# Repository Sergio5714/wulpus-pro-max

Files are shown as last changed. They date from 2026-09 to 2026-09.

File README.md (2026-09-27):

# WULPUS Pro Max
## Multi-mode Ultra-Low-Power Wearable Ultrasound Platform
> WULPUS Pro Max adopts the core analog front end of the original [WULPUS PRO design](https://github.com/pulp-bio/wulpus-pro), while extending its analog performance, firmware architecture, host connectivity, and software tooling. The project is independently developed and maintained by [Sergei Vostrikov](https://github.com/Sergio5714) and contributors.

<p align="center">
  WULPUS Pro Max main
  <br/>
  WULPUS Pro Max module with PolyCMUT transducer.
</p>

## Table of contents

- [Introduction](#introduction)
  - [Hardware photos](#hardware-photos)
  - [System diagram](#system-diagram)
  - [Specifications](#specifications)
- [Clone the repository](#clone-the-repository)
- [Structure of the repository](#structure-of-the-repository)
- [Documentation](#documentation)
- [Build Instructions](#build-instructions)
- [Host setup and operation](#host-setup-and-operation)
  - [WULPUS Pro Max WiFi host PCB (WiFi/USB CDC)](#wulpus-pro-max-wifi-host-pcb-wifiusb-cdc)
  - [WULPUS Pro Max + nRF52 DK + nRF Dongle (BLE)](#wulpus-pro-max--nrf52-dk--nrf-dongle-ble)
- [Citation](#citation)
- [Changelog](#changelog)
- [Authors](#authors)
- [License](#license)
  - [Limitation of Liability](#limitation-of-liability)

# Introduction

WULPUS Pro Max is a modular wearable ultrasound platform for research and
development. It combines a tightly integrated, flexible ultrasound acquisition
front end with a dedicated host board and a mature software stack. Together,
these components provide a complete path from transducer excitation and signal
acquisition to device control, data streaming, visualization, and analysis.

The modular architecture supports both wearable experiments and benchtop
operation:

- **Benchtop operation:** connect a single USB-C cable for power delivery,
  device configuration, and data transfer over USB CDC.
- **Wireless operation:** connect a LiPo battery with a 2-pin JST connector to the
  host board and use Wi-Fi/TCP for seamless, cable-free operation. The host
  board also provides integrated battery charging and protection.

> **Note:** The same USB-C cable can flash and update the entire device without
> external programming tools.

WULPUS Pro Max reliably delivers raw ultrasound data to the host system either
over the air or through a USB cable, with state-of-the-art pulse repetition
frequencies (PRFs) of up to **500 Hz**. The common Python software stack supports
both links, providing the same tools and workflows in either operating mode.

## Hardware photos

<table>
  <tr>
    <td colspan="2" align="center">
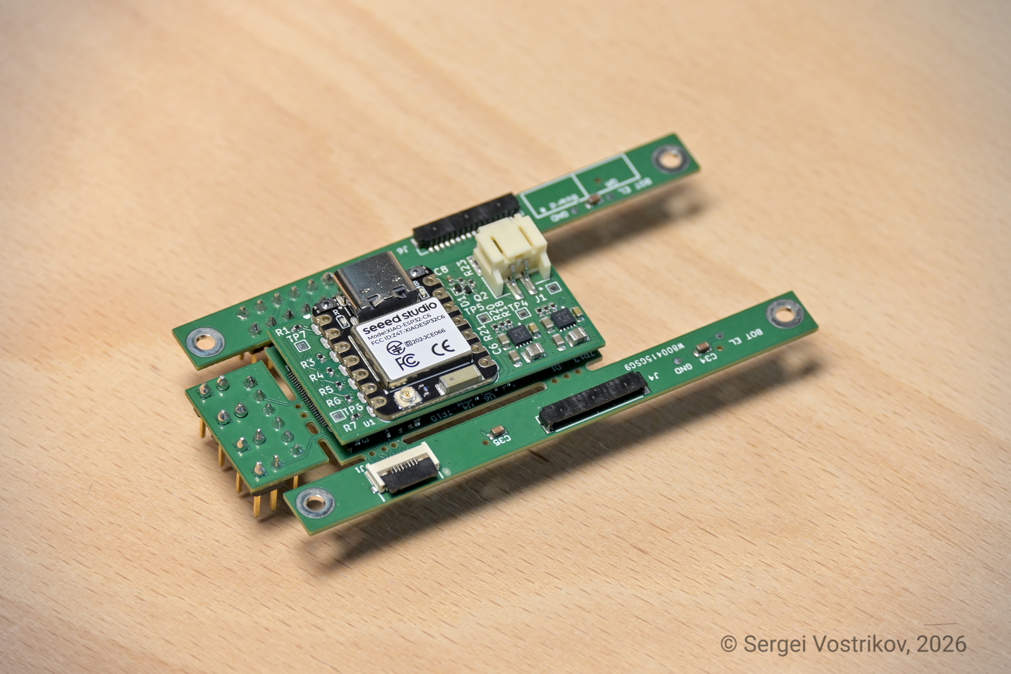
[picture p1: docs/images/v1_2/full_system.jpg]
WULPUS PRO Acquisition PCB connected to the WiFi host PCB
      
      <br/>
      Assembled WULPUS Pro Max system
    </td>
  </tr>
  <tr>
    <td width="50%" align="center">
      Top view of the WULPUS PRO Acquisition PCB
      <br/>
      WULPUS PRO Acquisition PCB<br/>
      (development version with test and debug headers)
    </td>
    <td width="50%" align="center">
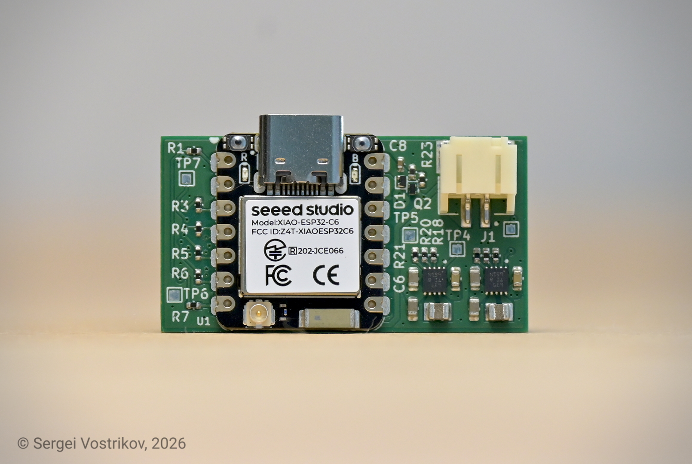
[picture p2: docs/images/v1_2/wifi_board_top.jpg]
Top view of the WULPUS Pro Max WiFi host PCB
      
      <br/>
      WULPUS Pro Max WiFi host PCB
    </td>
  </tr>
</table>

## System diagram

<p align="center">
  WULPUS Pro Max system diagram
  <br/>
  WULPUS Pro Max system diagram
</p>

## Specifications

WULPUS Pro Max builds on the original [WULPUS](https://github.com/Sergio5714/wulpus) platform and keeps the same low-power wearable ultrasound philosophy while making a substantial leap in specifications and extending the hardware and communication options. The table below compares the main features of WULPUS Pro Max with those of the original WULPUS platform.

| Feature | WULPUS<br>(v1.2.4) | WULPUS Pro Max |
| --- | --- | --- |
| Number of channels | 8, time-multiplexed | **16**, time-multiplexed |
| Supported transducers | PZT transducers | PZT transducers, **CMUTs** |
| Excitation amplitude | 15 V unipolar | **30 V** unipolar |
| Excitation frequency | ~100 kHz to 4 MHz | ~100 kHz to **10 MHz** |
| Transducer biasing | - | Indirect or direct **bias**, **-30 V or 30 V** |
| Analog front-end | 10 dB LNA + 30.8 dB PGA | 6 dB LNA + **70 dB VGA** |
| Receive-path<br>SNR | - | Approximately **45 dB** in the passband at 41.9 dB total gain;<br>**>=30 dB** at 3 MHz |
| Receive-path<br>bandwidth | &lt;1.4 MHz | Amplification-only: up to **14 MHz**;<br>end-to-end -3 dB: **1.4 MHz** |
| TGC support | No (fixed gain) | **Yes** (linear profile) |
| Maximum PRF | 50 Hz | **500 Hz**<br>(with WiFi host PCB over Wi-Fi/TCP or USB CDC) |
| Power budget at 50 Hz PRF | <=25 mW | <=40 mW |
| Data link | BLE | **USB**, **Wi-Fi**, or **BLE** |
| Form factor | 46 x 25 mm footprint | **40 x 20 mm** footprint |

Full WULPUS Pro Max specifications are available in [docs/full_specifications.md](docs/full_specifications.md).

# Clone the repository

Clone the public repository without its private development submodule:

```bash
git clone https://github.com/Sergio5714/wulpus-pro-max.git
```

The `hw/kicad_us_lib` submodule is an internal development library hosted in a
private repository. External users do not have access to it and do not need to
initialize it to use the released fabrication outputs. For editing the KiCad
designs, generate project-specific symbol and footprint libraries from the
symbols and footprints embedded in the corresponding project files. See the
[hardware README](hw/README.md#internal-kicad-library) for details.

Authorized developers can initialize the private submodule after cloning:

```bash
git submodule update --init --recursive
```

# Structure of the repository

The repository is organized into four top-level folders. See the README files
inside them for component-level details.

- [`hw`](hw) — PCB design and fabrication files.
- [`fw`](fw) — embedded firmware source code.
- [`sw`](sw) — Python software, graphical interfaces, and notebooks.
- [`docs`](docs) — project documentation and images.

# Documentation

- [Full system specifications](docs/full_specifications.md)
- [Host board options](docs/host_board_options.md)
- [PCB designs and fabrication](hw/README.md)
- Firmware:
  - [ESP32 host firmware](fw/esp32/README.md)
  - [MSP430 acquisition firmware](fw/msp430/README.md)
  - [Legacy nRF52 BLE firmware](fw/nrf52/README.md)
- [Python software and notebooks](sw/README.md)

For background information about the original WULPUS platform, see the
[legacy WULPUS User Manual](https://github.com/Sergio5714/wulpus/blob/main/docs/wulpus_user_manual.pdf).

# Build Instructions

The WULPUS Pro Max WiFi host PCB provides a one-cable setup and programming
workflow:

1. **Get hardware**

   Order the [Acquisition PCB](docs/images/v1_0/eval_board_main.jpg) and [WiFi host PCB](docs/images/v1_2/wifi_board_top.jpg) using the [PCBWay shared projects](hw/README.md#pcbway-shared-projects), or manufacture and assemble them yourself using the design files, schematics, and bills of materials linked in the [hardware guide](hw/README.md#included-pcb-designs).

2. **Install the host software**

   Follow the [Python software setup instructions](sw/README.md#how-to-get-started) on the host PC.

3. **Flash the firmware**

   - Connect the WiFi host PCB to the Acquisition PCB, then connect the host PCB to the PC with a single USB-C cable.
   - Follow the [firmware update guide](docs/firmware_update_guide.md) to install
     released ESP32 and MSP430 packages with the graphical updater.

   > No external programmer, adapter board, or additional programming cables are required for this workflow.

   > **Note:** The ESP32 and MSP430 firmware can be customized. Firmware
   > developers should follow the [ESP32 development guide](fw/esp32/docs/development_guide.md)
   > and [MSP430 development guide](fw/msp430/README.md#build-and-export-firmware)
   > to configure and compile custom images.

# Host setup and operation

WULPUS Pro Max supports multiple host-board configurations. See
[Host board options](docs/host_board_options.md) for a comparison. Instructions
for getting started with each configuration are provided below.

## WULPUS Pro Max WiFi host PCB (WiFi/USB CDC)

1. Connect the [WULPUS Pro Max WiFi host PCB](docs/images/v1_2/wifi_board_top.jpg) to the [Acquisition PCB](docs/images/v1_0/eval_board_main.jpg).
2. Connect the host PCB to the PC with a data-capable USB-C cable. This connection powers both PCBs.
3. Start Jupyter from the `sw` folder:

   ```bash
   uv run jupyter notebook
   ```

4. Open [`wulpus_pro_example.ipynb`](sw/wulpus_pro_example.ipynb) in the browser.
5. For a wired connection, select **USB CDC**, scan for devices, and open the ESP32-C6 port. For a wireless connection, first complete [WiFi provisioning](fw/esp32/docs/wifi_provisioning_guide.md), then select **WiFi** and discover the device.
6. Apply the acquisition configuration in the notebook and start acquisition.

For development with a standalone XIAO ESP32-C6, follow its [wiring and power requirements](fw/esp32/docs/development_guide.md#supported-boards) and the [pin mapping](fw/esp32/docs/development_guide.md#pin-mapping). This setup requires an Acquisition PCB with the MSP430 firmware already programmed.

## WULPUS Pro Max + nRF52 DK + nRF Dongle (BLE)

> The nRF52 BLE option may suit applications that need even lower power
> consumption than the WiFi host solution. It is a legacy, unsupported option
> and is not recommended for new setups. Using it requires additional
> integration work, including manual wiring, external power, and a separate
> programmer for the MSP430.

1. Connect the nRF52 DK to the Acquisition PCB using the pin mapping documented in [fw/nrf52/README.md](fw/nrf52/README.md).
2. Plug in the USB dongle and power the nRF52 DK via USB.
3. Check the dongle connection. The green LED should light up. If it does not, press the reset button on the nRF52 DK and try again.
4. After confirming dongle connectivity, power the Acquisition PCB through the connector or debug pin headers.
5. Start Jupyter from the `sw` folder:

   ```bash
   uv run jupyter notebook
   ```

6. Open [`wulpus_pro_example.ipynb`](sw/wulpus_pro_example.ipynb) in the browser, select **BLE**, and follow the notebook instructions to begin acquisition. Older notebook variants are archived under `sw/legacy`.

# Citation

Please cite our [arXiv preprint](https://arxiv.org/abs/2607.12137):

```bibtex
@article{vostrikov2026wulpuspro,
  title={WULPUS PRO: Multi-mode Ultra-Low-Power Wearable Ultrasound and Array Imaging with CMUT Support},
  author={Vostrikov, Sergei and Villani, Federico and Hirschi, Cedric and Lu, Jinhao and Welsch, Jonas and Angerer, Martin and Cretu, Edmond and Rohling, Robert and Cossettini, Andrea and Benini, Luca},
  journal={arXiv preprint arXiv:2607.12137},
  year={2026},
  url={https://arxiv.org/abs/2607.12137}
}
```

If you would like to cite this repository, please use:

```bibtex
@misc{wulpus_pro_repo_sergio5714_2026,
  title={WULPUS Pro Max: Multi-mode Ultra-Low-Power Wearable Ultrasound Platform (Independently Maintained)},
  author={Vostrikov, Sergei and Villani, Federico and Hirschi, Cedric and Cossettini, Andrea and Benini, Luca},
  year={2026},
  howpublished={GitHub repository},
  url={https://github.com/Sergio5714/wulpus-pro-max}
}
```

# Changelog

See [CHANGELOG.md](CHANGELOG.md) for release notes and main project changes.

# Authors

Since 2025,
[Sergei Vostrikov](https://scholar.google.com/citations?user=a0KNUooAAAAJ&hl=en)
(@Sergio5714) has independently maintained this repository and continued
developing WULPUS Pro Max, with contributions from others.

The initial WULPUS PRO system was developed from 2024 to 2025 as a research
project at the [Integrated Systems Laboratory (IIS)](https://iis.ee.ethz.ch/)
at ETH Zurich by:

- [Sergei Vostrikov](https://scholar.google.com/citations?user=a0KNUooAAAAJ&hl=en) (PCB design, firmware, software, open-sourcing)
- [Federico Villani](https://scholar.google.com/citations?user=5LgLMCEAAAAJ&hl=en) (PCB design, component selection)
- [Cedric Hirschi](https://www.linkedin.com/in/c%C3%A9dric-cyril-hirschi-09624021b/) (firmware, software)
- [Andrea Cossettini](https://scholar.google.com/citations?user=d8O91jIAAAAJ&hl=en) (supervision, project administration)
- [Luca Benini](https://scholar.google.com/citations?hl=en&user=8riq3sYAAAAJ) (supervision, project administration)

Additional contributors to the project were:

- [Sebastian Frey](https://scholar.google.com/citations?user=7jhiqz4AAAAJ&hl=en), ETH Zürich (design review)
- [Alfonso Blanco Fontao](https://www.linkedin.com/in/alfonso-blanco-fontao-b6214726/), ETH Zürich (design review, PCB fabrication coordination)
- [Ciara Giles Doran](https://www.linkedin.com/in/ciaragilesdoran/) (preliminary evaluation of the AD8338 VGA)

# License

The following files are released under Apache License 2.0 (`Apache-2.0`) (see `sw/LICENSE`):

- `sw/`

The hardware designs are released under Solderpad v0.51 (`SHL-0.51`):

- `hw/`

See the [hardware license table](hw/README.md#license) for the applicable license file and copyright holder for each PCB design.

Project-authored firmware code is generally licensed under Apache-2.0, as
identified in the source-file headers. Bundled vendor and third-party code
retains its original license, including BSD-style terms for Texas Instruments
sources and the Nordic Semiconductor license for Nordic SDK sources. See the
license notices and source headers in `fw/esp32/`, `fw/msp430/`, and `fw/nrf52/`
for the terms that apply to each file.

## Limitation of Liability

In no event and under no legal theory, whether in tort (including negligence), contract, or otherwise, unless required by applicable law (such as deliberate and grossly negligent acts) or agreed to in writing, shall any Contributor be liable to You for damages, including any direct, indirect, special, incidental, or consequential damages of any character arising as a result of this License or out of the use or inability to use the Work (including but not limited to damages for loss of goodwill, work stoppage, computer failure or malfunction, or any and all other commercial damages or losses), even if such Contributor has been advised of the possibility of such damages.

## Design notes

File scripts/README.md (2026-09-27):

# Development scripts

This directory contains maintainer and firmware-development utilities. Run all
commands from the repository root.

## Prerequisites

Follow the authoritative setup and build instructions before using these
scripts:

- [Python software setup](../sw/README.md#how-to-get-started)
- [ESP32 firmware development](../fw/esp32/docs/development_guide.md)
- [MSP430 firmware development](../fw/msp430/README.md#build-and-export-firmware)

The packaging scripts do not compile firmware. They validate and package the
outputs produced by these toolchains.

## ESP32 formatting

Check the formatting of project-owned ESP32 C sources:

```powershell
uv run --project sw python scripts/format_esp32_fw.py --check
```

`--check` only reports formatting differences and does not create or modify any
files. Apply formatting with:

```powershell
uv run --project sw python scripts/format_esp32_fw.py --fix
```

`--fix` modifies the project-owned `.c` and `.h` files in place under
`fw/esp32/main/` and `fw/esp32/components/`. It does not generate a separate
output file. Third-party sources under
`fw/esp32/components/msp430_programmer/ti/` are excluded.

## ESP32 release package

After building the XIAO ESP32-C6 firmware in `fw/esp32/build-xiao`, create the
validated release ZIP:

```powershell
uv run --project sw python scripts/package_esp32_release.py
```

The script reads these compiled files by default:

```text
fw/esp32/build-xiao/
|-- bootloader/bootloader.bin
|-- partition_table/partition-table.bin
`-- wulpus-pro-fw.bin
```

It creates the ignored `releases/` directory when needed and writes exactly one
release artifact:

```text
releases/wulpus-pro-max-esp32-<version>.zip
```

The ZIP contains:

```text
manifest.json
bootloader.bin
partition-table.bin
wulpus-pro-fw.bin
```

`manifest.json` contains the firmware version, ESP32-C6 target, flash settings,
fixed image offsets, and a SHA-256 hash for every binary.

Use `--build-dir PATH` to read build files from a different directory or
`--output FILE.zip` to select another output path. Packaging verifies that the
version embedded in `wulpus-pro-fw.bin` matches
`fw/esp32/firmware_version.txt`.

## MSP430 release package

Build the MSP430 **Debug** configuration in Code Composer Studio, then package
the generated TI-TXT image:

```powershell
uv run --project sw python scripts/package_msp430_release.py
```

By default, the script recursively searches
`fw/msp430/wulpus_msp430_firmware/` for a TI-TXT `.txt` or `.titxt` build. A
normal CCS Debug build is found at:

```text
fw/msp430/wulpus_msp430_firmware/Debug/wulpus_pro_msp430_firmware.txt
```

The script verifies its compiled firmware version against
`wulpus/firmware_version.h` and the MSP430 changelog. It also locates the TI
MSP430 21.6.0.LTS compiler used by the project and packages its original RTS
manifest and SPDX inventory with the DriverLib license. It creates the ignored
`releases/` directory when needed and writes two files:

```text
releases/
|-- wulpus-pro-max-msp430-<version>.zip
`-- wulpus-pro-max-msp430-<version>.zip.sha256
```

The ZIP contains the validated `.mspfw` image consumed by the ESP32 updater,
`SHA256SUMS.txt`, the project license, `THIRD_PARTY_NOTICES.txt`, and original
TI compliance files under `LICENSES/`. The adjacent `.sha256` file verifies the
complete release ZIP.

If more than one TI-TXT build exists, select it explicitly:

```powershell
uv run --project sw python scripts/package_msp430_release.py `
  --input path\to\wulpus_pro_msp430_firmware.txt
```

Use `--search-dir PATH` to change automatic discovery or `--output-dir PATH`
to place both generated files elsewhere. If the compiler is not in a standard
CCS installation directory, pass `--ti-compiler-dir PATH` or set
`TI_MSP430_CGT_DIR` to `ti-cgt-msp430_21.6.0.LTS`.

## PCB fabrication packages

Before packaging, manually regenerate and review all fabrication outputs and
documentation from the PCB source projects. In particular, regenerate the
KiCad fabrication and documentation outputs for the WiFi host PCB. This script
does not run KiCad, Altium Designer, design-rule checks, or output jobs.

Package the Acquisition PCB and WiFi host PCB:

```powershell
uv run --project sw python scripts/package_pcb_releases.py
```

The script reads only the `fabrication_outputs/` and `docs/` directories from
the two PCB projects. It creates four ignored release artifacts:

```text
releases/
|-- wulpus-pro-max-acquisition-pcb-1.0.0.zip
|-- wulpus-pro-max-acquisition-pcb-1.0.0.zip.sha256
|-- wulpus-pro-max-wifi-host-pcb-1.0.1.zip
`-- wulpus-pro-max-wifi-host-pcb-1.0.1.zip.sha256
```

The Acquisition PCB ZIP also contains `LICENSE_ETH`. The WiFi host PCB ZIP
also contains `CHANGELOG.md` and `LICENSE`. No editable PCB source files,
backup directories, firmware, or library files are included. Use
`--acquisition-version`, `--wifi-host-version`, or `--output-dir` to override
the defaults. The WiFi host version must match its latest changelog release.

## Installing release packages

This directory only documents development and packaging utilities. For the
supported graphical ESP32 and MSP430 update workflow, follow the
[firmware-update instructions](../docs/firmware_update_guide.md).

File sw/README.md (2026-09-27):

# WULPUS Pro Max software
This directory contains the WULPUS Pro Max Python API, graphical user interface components, Wi-Fi and serial transports, and example Jupyter notebooks.

`wulpus_pro_example.ipynb` is the supported main notebook for USB CDC, Wi-Fi,
and BLE operation. Older specialized notebooks are retained for reference in
`legacy/` and are not part of the current workflow.

The supported configuration implementation is the WULPUS Pro Max stack:

- `wulpus/rx_tx_conf_pro.py`: 16-channel TX/RX mask generation
- `wulpus/uss_conf_pro.py`: acquisition configuration and packet encoding
- `wulpus/config_package_pro.py`: configuration field definitions
- `wulpus/uss_conf_gui_pro.py`: configuration widgets
- `wulpus/gui.py`: transport-independent acquisition and visualization GUI
- `wulpus/wifi_link.py`: robust TCP transport and acquisition lifecycle
- `wulpus/wifi_discovery.py`: mDNS discovery
- `wulpus/usb_cdc_link.py`: native ESP32-C6 USB CDC transport
- `wulpus/ble_dongle.py`: legacy BLE-dongle serial transport
- `wulpus/device_config_gui.py`: persistent ESP32 configuration over USB CDC
- `wulpus/esp32_update.py`: validated ESP32-C6 release packages and flashing
  through uv-managed esptool
- `wulpus/msp430_update.py`: TI-TXT packaging, MSP430 upload, status,
  diagnostics, and update widgets over USB CDC or Wi-Fi
- `wulpus/npz_viewer.py`: interactive acquisition-file inspection and signal processing

`WulpusGuiSingleCh` depends on the `WulpusProCommunicationLink` protocol rather than a concrete transport, so it can operate with `WulpusBleDongle`, `WulpusProWiFiLink`, or `WulpusProUsbCdcLink`.

The ESP32 device-configuration section in `wulpus_pro_example.ipynb` uses
`WulpusProDeviceConfigGUI` to load and replace non-secret configuration over
USB CDC, set or clear write-only Wi-Fi credentials, and reboot to apply changes.
The GUI never reads stored SSIDs or passwords.

## Firmware updates

Use [`wulpus_pro_firmware_update.ipynb`](wulpus_pro_firmware_update.ipynb) to
flash a packaged ESP32-C6 release without installing ESP-IDF. Install the
flashing dependency with `uv sync --group flash`, close every client using the
COM port, and select the release ZIP in the ESP32 panel.

The same notebook retains the separate MSP430 updater. Select the released
MSP430 ZIP; the GUI verifies its firmware checksum and container before upload.
TI-TXT and standalone `.mspfw` files remain available for development. Click
**Upload and program**. Commit reboots the ESP32; programming happens before
normal connectivity returns. **Check status** retrieves the persisted result.
`COMPLETE` confirms programming/verification, not application health. Wiring,
partition requirements, Wi-Fi API usage, and recovery are documented in the
[firmware update guide](../docs/firmware_update_guide.md).

## Interactive NPZ viewer

Use `WulpusProNpzViewer` in Jupyter to inspect files saved by either the GUI or
the USB profiler. Select a local `.npz` using the upload control, filter frames
by TX/RX configuration, and move through matching acquisitions with the slider.
Raw, GUI-equivalent band-pass-filtered, and Hilbert-envelope traces can be
shown independently. Set the sampling-frequency control to the value used for
the acquisition because the legacy NPZ format does not store it. Set the
acquisition slider to any filtered frame and press **Replay** to advance from
that position at the selected FPS; replay ends at the final matching frame or
when **Stop** is pressed. The Y-axis range is locked when replay starts so
amplitude changes do not rescale the plot during playback:

```python
%matplotlib widget
from wulpus.npz_viewer import WulpusProNpzViewer

viewer = WulpusProNpzViewer()
viewer
```

Files on the Jupyter server can also be opened directly:

```python
viewer = WulpusProNpzViewer("data_0.npz")
viewer
```

## USB CDC operation

Select **USB CDC** in the example GUI when the XIAO ESP32-C6 is connected
directly to the PC. The link scans for the Espressif USB Serial/JTAG CDC port
and runs the same WULPUS command and RF-frame protocol used by Wi-Fi.

Only one application can own the COM port. Before flashing or opening IDF
Monitor, stop acquisition and close the device in the GUI. Flash normally with:

```powershell
idf.py -p COM9 flash
```

Replace `COM9` with the detected port. Reopen it in the GUI after the ESP32
restarts. JTAG is a separate interface of the ESP32-C6 composite USB device and
remains available, although halting the CPU interrupts live acquisition.

### USB frame-rate profiling

Close the GUI and all serial monitors, then run the standalone profiler with
explicit acquisition periods. TX is disabled by default, so this exercises the
capture and USB transport without firing the pulser:

```powershell
uv run python profile_usb_fps.py --port COM9 --period-us 10000 5000 2000 --frames 500
```

The profiler reports target and measured FPS, 95th-percentile frame latency,
timeouts, and acquisition-number gaps. The fastest passing period is the
maximum stable rate among the values tested. The `simplified` preset disables
TX/RX masks and uses a +1 ms DC-DC margin. The `active-all` preset selects all
channels and fixes DC-DC turn-on at 100 us. Custom and saved configurations use
their explicitly selected timing and masks. Enabling TX requires an
independently verified safe pulse-repetition rate for the connected hardware
and transducer.

To reproduce a configuration saved by the acquisition GUI, pass its JSON file.
The saved measurement period is used when `--period-us` is omitted:

```powershell
uv run python profile_usb_fps.py --port COM10 --config uss_config_pro.json --frames 2000
```

Add `--output acquisition.npz` to save the measured frames in the same format
as the GUI, with the `data_arr`, `acq_num_arr`, and `tx_rx_id_arr` arrays. Warmup
frames are not saved. When profiling multiple periods, the profiler appends the
period to each filename, for example `acquisition_2000us.npz`.

Specify `--period-us` to override only the saved period for a rate sweep. New
GUI configuration files include TX/RX mask arrays. Legacy files without masks
remain compatible and use one zero-mask TX/RX configuration unless masks or a
profiler mode are supplied explicitly.

### Runtime status

The TCP and USB CDC links expose the same ESP32 diagnostic API:

```python
status = link.get_status()
print(hex(status.error_flags), status.current_buffer_usage)

# Clear all sticky errors while preserving lifetime counters.
link.clear_status()

# Clear sticky errors and reset diagnostic counters.
link.clear_status(clear_counters=True)
```

The status snapshot includes acquisition-buffer overflow, SPI and link errors,
DATA_READY/SPI/transmitted-frame counters, discarded frames, and current and
maximum DMA-buffer occupancy.

# How to get started?

Install dependencies with `uv` and launch Jupyter from this folder:

```bash
uv sync
uv run jupyter notebook
```

In the Jupyter browser, open `wulpus_pro_example.ipynb`. It is the main
supported workflow for USB CDC, Wi-Fi, and BLE operation.

For more details, see `sw/how_to_install_dependencies.md`.

## Wi-Fi example on Windows

The `wulpus_pro_example.ipynb` notebook discovers the ESP32 through the
`_wulpus_pro._tcp.local.` mDNS service and communicates with it over TCP port 2121.
The computer and WULPUS Pro Max must be connected to the same local network.

Windows may block mDNS or the TCP connection when the network profile is
**Public**. On a trusted network, either change its profile to **Private**, or
open PowerShell as Administrator and add narrowly scoped rules for the Python
interpreter used by this project's virtual environment:

```powershell
# Run from the repository's sw directory.
$pythonPath = (Resolve-Path ".\.venv\Scripts\python.exe").Path

New-NetFirewallRule `
    -DisplayName "WULPUS Pro Max mDNS discovery" `
    -Direction Inbound `
    -Action Allow `
    -Program $pythonPath `
    -Protocol UDP `
    -LocalPort 5353 `
    -RemoteAddress LocalSubnet `
    -Profile Public

New-NetFirewallRule `
    -DisplayName "WULPUS Pro Max TCP communication" `
    -Direction Outbound `
    -Action Allow `
    -Program $pythonPath `
    -Protocol TCP `
    -RemotePort 2121 `
    -RemoteAddress LocalSubnet `
    -Profile Public
```

The active notebook interpreter can be checked with:

```python
import sys
print(sys.executable)
```

After changing the network profile or firewall rules, restart the notebook
kernel and reset the ESP32. If multicast service discovery remains unavailable,
`WulpusProWiFiLink.get_available()` also attempts to resolve `wulpus_pro.local`.
The ESP32 IP address can additionally be supplied manually using
`WulpusProWiFiDevice` as shown in the example notebook.

To remove the firewall rules later:

```powershell
Remove-NetFirewallRule -DisplayName "WULPUS Pro Max mDNS discovery"
Remove-NetFirewallRule -DisplayName "WULPUS Pro Max TCP communication"
```

# License
The source files are released under Apache v2.0 (`Apache-2.0`) license unless noted otherwise, please refer to the `sw/LICENSE` file for details.

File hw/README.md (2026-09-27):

# WULPUS Pro Max PCB design files

This directory contains the PCB designs used by WULPUS Pro Max. The source files are
provided in Altium Designer or KiCad format, depending on the board. Where
available, each project also includes PDF schematics and assembly drawings under
`docs`, and production-ready files under `fabrication_outputs`, including bills
of materials, Gerber files, NC drill files, and pick-and-place files.

## Included PCB designs

### WULPUS PRO Acquisition PCB

Directory: [`wulpus_pro_acq_pcb_dev_board`](wulpus_pro_acq_pcb_dev_board)

The WULPUS PRO Acquisition PCB is the platform's ultrasound acquisition and
pulser board. It contains
the transmit and receive signal paths, high-voltage switching, power supplies,
MSP430 control circuitry, and the host interface. The design sources are provided
in Altium Designer format. This board is required to build a WULPUS Pro Max
system.

### WULPUS Pro Max WiFi host PCB

Directory: [`wulpus_wifi_host_pcb`](wulpus_wifi_host_pcb)

An open-source companion board that integrates wireless communication, power
delivery, and firmware programming for the WULPUS PRO Acquisition PCB. Based
on the [Seeed Studio XIAO ESP32-C6](https://www.seeedstudio.com/Seeed-Studio-XIAO-ESP32C6-p-5884.html),
it supports runtime acquisition configuration and real-time ultrasound data
streaming over Wi-Fi/TCP or native USB CDC at pulse repetition frequencies
(PRFs) of up to 500 Hz. It is the primary host board for WULPUS Pro Max and runs
the [ESP32 firmware](../fw/esp32).

A single USB-C connection powers the complete system and enables wired
communication and firmware updates, including [programming the acquisition
board's MSP430 through integrated JTAG](../docs/firmware_update_guide.md).
The host supports Wi-Fi provisioning, automatic reconnection, and device
discovery. The platform can also be powered by an external Adafruit battery
with a standard JST connector. USB battery charging is supported, and battery
protection is integrated.

The design sources are provided in KiCad format, together with fabrication and
assembly outputs.

Using the XIAO module provides a stable, actively supported wireless platform
with a proven RF design. Seeed publishes compliance records for the
module, including [FCC Part 15](https://files.seeedstudio.com/Seeed_Certificate/documents_certificate/113991254-FCC.pdf)
and [CE RED](https://files.seeedstudio.com/Seeed_Certificate/documents_certificate/113991254-CE.pdf)
testing. This pre-tested module significantly reduces RF design effort and
compliance risk compared with developing a custom, uncertified RF implementation.

### polyCMUT adapter board

Directory: [`wulpus_polycmut_adapter`](wulpus_polycmut_adapter)

An optional research adapter for connecting polyCMUT transducers to WULPUS. The
design sources are provided in Altium Designer format. This board is not required
for standard WULPUS Pro Max operation.

## Internal KiCad library

The [`kicad_us_lib`](kicad_us_lib) directory is referenced as a Git submodule and
contains the internal KiCad symbols, footprints, and related library assets used
to develop the hardware designs. It is hosted in a private repository and is
intended only for internal development; external users will not have access to
it. The library could not be made publicly open source because some of its
contents are subject to third-party licensing restrictions.

The released KiCad projects embed the symbols and footprints used by each
design. External users are advised to generate their own project-specific symbol
and footprint libraries from the corresponding project files instead of relying
on `kicad_us_lib`. The released fabrication outputs can be used without the
private submodule.

## PCBWay shared projects

For convenient one-click PCB production and assembly, you can use the PCBWay shared projects:

- [WULPUS PRO Acquisition PCB v1.0.0](https://www.pcbway.com/project/shareproject/WULPUS_PRO_Evaluation_board_v1_0_0_992d7510.html)

- [WULPUS PRO WiFi host PCB v1.0.0](https://www.pcbway.com/project/shareproject/WULPUS_PRO_WiFi_host_PCB_7cfe7806.html)

This option is convenient for outsourced PCB production and assembly, with an estimated **~1 month lead time** and a price of about **220 USD** per probe for Acquisition PCB and **40 USD** for the WiFi host PCB, based on mid-2026 pricing.

## License

All three PCB designs are released under the Solderpad Hardware License v0.51
(`SHL-0.51`). They use separate license files because their copyright holders
differ:

| PCB design | Directory | License file | Copyright |
| --- | --- | --- | --- |
| WULPUS PRO Acquisition PCB | [`wulpus_pro_acq_pcb_dev_board`](wulpus_pro_acq_pcb_dev_board) | [`LICENSE_ETH`](LICENSE_ETH) | Copyright (C) 2025 ETH Zurich. All rights reserved. |
| WULPUS polyCMUT adapter | [`wulpus_polycmut_adapter`](wulpus_polycmut_adapter) | [`LICENSE_ETH`](LICENSE_ETH) | Copyright (C) 2025 ETH Zurich. All rights reserved. |
| WULPUS Pro Max WiFi host PCB | [`wulpus_wifi_host_pcb`](wulpus_wifi_host_pcb) | [`LICENSE`](LICENSE) | Copyright (C) 2026 Sergei Vostrikov. All rights reserved. |

The license terms are otherwise identical. The internal `kicad_us_lib`
submodule contains third-party material and is not covered by this table; its
contents retain their respective license terms.

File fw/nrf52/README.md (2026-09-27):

# WULPUS PRO source files for nRF52 DK BLE MCU firmware projects
This directory contains the source files for 
- nRF52832 BLE MCU (`fw/nrf52/ble_peripheral`) used by nRF52 DK.
- nRF52840 Dongle (`fw/nrf52/peripheral`) used to receive the ultrasound data on a host PC.

# How to get started?

Please refer to the `WULPUS User Manual` of the WULPUS system v 1.2.2 for the instructions on how to flash the BLE MCU and USB Dongle:
`https://github.com/Sergio5714/wulpus/blob/main/docs/wulpus_user_manual.pdf`

### Interconnect with nRF52 DK

Use the following pin mapping to connect the WULPUS PRO Acquisition PCB to the **nRF52 DK**:

| **Signal** | **nRF52 DK Pin** | **WULPUS PRO Connector Pin** |
|---|---|---|
| `SPI_SS` | P0.04 | X3.4 |
| `SPI_CLK` | P0.29 | X3.3 |
| `SPI_MISO` | P0.30 | X3.1 |
| `SPI_MOSI` | P0.31 | X3.2 |
| `Data_ready` | P0.24 | X4.2 |
| `BLE_conn_ready` | P0.25 | X4.3 |

# License
The files in the `fw/nrf52/ble_peripheral` and `fw/nrf52/peripheral` directories contain third-party sources that come with their own licenses. See the respective folders and source files' headers for the licenses used.

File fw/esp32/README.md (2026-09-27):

# WULPUS Pro Max ESP32 firmware

This ESP-IDF firmware connects the Acquisition PCB to a PC through
either Wi-Fi/TCP or the native USB Serial/JTAG CDC interface of an ESP32-C6.
Both transports use the same framed binary protocol and can remain available
concurrently, while session arbitration ensures that only one host controls the
Acquisition PCB at a time.

## Overview

### Host board

The **[WULPUS Pro Max WiFi host PCB](../../hw/wulpus_wifi_host_pcb)** is the primary
host board for this firmware. It contains a Seeed Studio XIAO ESP32-C6 and uses
the XIAO board configuration in this project. A standalone XIAO ESP32-C6 is
supported as a development alternative.

### Main functions

- **Runtime MSP430 configuration and ultrasound data acquisition:** sends
  acquisition settings and receives ultrasound frames through SPI with DMA.
- **Real-time data streaming over Wi-Fi or USB CDC:** selects the active
  transport at runtime through protocol sessions, with one controlling host
  at a time.
- **Persistent ESP32 configuration:** stores device boot policy, Wi-Fi settings,
  and credentials across power cycles; changes take effect after reboot.
- **MSP430 flashing:** accepts firmware images over USB/TCP and programs the
  MSP430FR5043 through four-wire JTAG.
- **Wi-Fi provisioning and discovery:** supports SoftAP setup, automatic
  reconnection, and mDNS discovery by the host application.
- **Buffering and diagnostics:** buffers acquisition frames and reports SPI,
  transport, and buffer errors, frame counters, and MSP430 update results.

> MSP430 firmware flashing is available only with the WULPUS Pro Max WiFi host PCB;
> it is not available with a standalone XIAO ESP32-C6.

## Reference documentation

### Build and installation

- [ESP-IDF toolchain setup](docs/esp_idf_toolchain_guide.md) — installation on Windows,
  Linux, and macOS, VS Code configuration, environment activation, verification,
  and troubleshooting.
- [Development guide](docs/development_guide.md) — requirements, board configuration,
  building, flashing, and creating a merged firmware image.

### Operation and configuration

- [MSP430 updater implementation](docs/msp430_update_guide.md) — staging,
  boot-time JTAG programming, verification, diagnostics, and recovery behavior.
- [Wi-Fi provisioning](docs/wifi_provisioning_guide.md) — first boot, SoftAP parameters,
  credential storage, reconnection, reprovisioning, and USB availability.

### Architecture and protocols

- [Firmware architecture](docs/firmware_architecture.md) — components, threads, data and
  control paths, DMA frame buffering, session lifecycle, and USB/Wi-Fi switching.
- [ESP32-to-MSP430 acquisition protocol](docs/msp430_acq_protocol.md) — SPI electrical settings,
  DATA_READY handshake, configuration-package fields, timing conversions,
  restart behavior, and RF frame layout.
- [ESP32-to-PC protocol](docs/esp32_pc_protocol.md) — USB/TCP framing, commands,
  acknowledgements, acquisition packets, status flags, and diagnostic counters.
- [MSP430 firmware update protocol](docs/msp430_update_protocol.md) — image
  upload commands, update states, and JTAG diagnostics.

### Project history

- [Firmware changelog](CHANGELOG.md)

## Authors

- Sergei Vostrikov
- Cedric Hirschi, ETH Zurich

## License

Project source files are licensed under the terms stated in their headers and
the repository license files. ESP-IDF and its third-party components retain
their respective licenses.

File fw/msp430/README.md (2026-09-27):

# WULPUS Pro Max source files for MSP430 Ultrasound MCU firmware project
This directory contains the source firmware files for 
- MSP430FR5043 Ultrasound MCU (`fw/msp430/wulpus_msp430_firmware`) mounted on the WULPUS Pro Max PCB

# Build and export firmware

Install Code Composer Studio with the TI MSP430 21.6 compiler family.
Import `wulpus_msp430_firmware` into Code Composer Studio as an existing CCS
project. Its CCS project name is `wulpus_pro_msp430_firmware` and it uses the TI
MSP430 21.6 compiler family. Build **Debug** to produce the `.out` executable
and a TI-TXT image: the Debug configuration now enables the MSP430 Hex Utility
with TI-TXT output and 8-bit memory/ROM widths. Release does not currently
enable that export step. The project preferences allow flexible compiler/product
version matching, so pin the installed toolchain for reproducible builds.

# Flashing

For the WiFi host PCB, follow the user-facing
[firmware update guide](../../docs/firmware_update_guide.md).

An MSP-FET can alternatively program the MSP430 using the procedure in the
legacy [WULPUS User Manual](https://github.com/pulp-bio/wulpus/blob/main/docs/wulpus_user_manual.pdf).
Before connecting the programmer, verify the MSP-FET pin mapping against the
Acquisition PCB schematic and connector pinout.
Disconnect the MSP-FET when using the ESP32 as the JTAG programmer.

# License
This directory contains third-party sources with their own licenses (primarily
BSD and Apache 2.0). See the respective folders and source headers, including
[`driverlib/license.txt`](wulpus_msp430_firmware/driverlib/license.txt). Firmware
releases must include applicable notices for bundled code and linked runtime
libraries. A compiler change does not remove those dependency obligations.

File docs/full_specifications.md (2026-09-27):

# WULPUS Pro Max Full Specifications

Most specifications on this page are derived from measurements reported in the official [WULPUS PRO arXiv preprint](https://arxiv.org/abs/2607.12137).

## Transducer and transmit path

| Feature | Specification |
| --- | --- |
| Channels | 16, time-multiplexed |
| Transducer support | PZT transducers and CMUTs |
| Transducer bias | Indirect or direct bias, -30 V or 30 V |
| Excitation amplitude | 30 V unipolar |
| Excitation frequency | 100 kHz to 10 MHz |

## Receive path

| Feature | Specification |
| --- | --- |
| Analog front-end | 6 dB LNA + 70 dB VGA |
| Time gain compensation | TGC up to 70 dB depth-dependent attenuation compensation |
| Envelope extraction | Optional LTC5507-based envelope detector, runtime configurable |
| Envelope detector bandwidth | Up to 1.5 MHz envelope bandwidth |
| Amplification-only bandwidth | Up to 14 MHz |
| End-to-end -3 dB bandwidth | 1.4 MHz (bounded by MSP430) |
| Passband SNR | Approximately 45 dB at 41.9 dB total gain |
| SNR at 3 MHz | >=30 dB |
| Maximum SINAD | 41 dB at 1 MHz (25.3 mV input);<br>35 dB at 2.25 MHz (31.6 mV input) |
| ENOB (based on SINAD) | Approximately 6.5 bits at 1 MHz;<br>approximately 5.5 bits at 2.25 MHz |

## Acquisition and data link

| Feature | Specification |
| --- | --- |
| ADC | 8 Msps analog-to-digital converter, 12-bit resolution |
| Host interface | SPI, 8 MHz |
| Maximum PRF | 500 Hz |
| Raw streaming FPS<br>(400 samples per acquisition) | USB (500 Hz)<br>Wi-Fi (500 Hz)<br>BLE (50 Hz, legacy) |

## Power

| Feature | Specification |
| --- | --- |
| Power budget | <=40 mW at 50 Hz PRF (with BLE host) |
| Core electronics power<br>(Acquisition PCB) | 35 mW (50 Hz PRF)<br>58 mW (300 Hz PRF) |
| Battery-life reference<br>(BLE host) | More than 24 hours of continuous raw data streaming<br>at 50 Hz PRF from a 300 mAh Li-Po battery|

## Imaging performance

| Feature | Specification |
| --- | --- |
| B-mode frame rate | 18 FPS using 16-channel synthetic-aperture acquisition at 300 Hz PRF |
| B-mode axial resolution | ~ 0.7 mm with a 2.25 MHz transducer (LA-2.25-32, Vermon) |
| B-mode lateral resolution | ~ 2.3 mm at the center with a 2.25 MHz transducer (LA-2.25-32, Vermon) |

## Mechanics

| Feature | Specification |
| --- | --- |
| Acquisition PCB size | 39 x 21 x 6 mm |
| Acquisition PCB weight | 5 g |
| WiFi host PCB size | 39 x 21 x 7 mm |
| WiFi host PCB weight | 5 g |

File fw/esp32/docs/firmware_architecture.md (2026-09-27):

# Firmware architecture

The ESP32 firmware bridges a WULPUS PRO Acquisition PCB to one PC host over
either native USB CDC or Wi-Fi/TCP. Transport selection is dynamic: USB and TCP
listen concurrently, but only one valid protocol session can control the board
at a time.

## Contents

- [Component layout](#component-layout)
- [Application threads](#application-threads)
- [Acquisition data path](#acquisition-data-path)
- [Control path](#control-path)
- [USB and Wi-Fi session switching](#usb-and-wi-fi-session-switching)
- [Acquisition state machine and MSP430 handshake](#acquisition-state-machine-and-msp430-handshake)
- [USB management](#usb-management)

## Component layout

| Path | Responsibility |
|---|---|
| `main/app_main.c` | Initialize components and start application threads. |
| `components/bsp` | Initialize the XIAO board and control its status LED. |
| `components/board` | Board GPIO, MSP430 reset, DATA_READY interrupt, SPI DMA, and USB light-sleep lock. |
| `components/frames` | Fixed pool of DMA-capable acquisition buffers. |
| `components/control` | Active session, acquisition state, sticky errors, and diagnostic counters. |
| `components/protocol` | PC protocol headers, commands, validation, and status structures. |
| `components/links` | Common ordered byte-stream interface plus USB and TCP adapters. |
| `components/sock` | TCP socket creation, listening, transfer, and synchronization. |
| `components/threads` | Long-running acquisition, protocol, transport, transmission, and provisioning tasks. |
| `components/provisioner` | Wi-Fi station setup and SoftAP provisioning workflow. |
| `components/persistent_config` | Versioned device-wide boot policy stored in NVS. |
| `components/mdns_manager` | Network discovery for the TCP service. |
| `components/msp430_programmer` | Image staging, validation, boot-time four-wire JTAG programming, and persisted update results/diagnostics. |

Acquisition GPIO/SPI operations stay in `components/board`; application threads
do not manipulate those peripherals directly. The MSP430 programmer owns its
configured TEST and JTAG GPIOs while programming.

## Application threads

| Thread | Default priority | Role |
|---|---:|---|
| `acquisition` | 8 | Sole acquisition SPI and MSP430 handshake owner. Executes queued commands and receives frames. |
| `protocol` | 6 | Sole reader of the active link. Parses PC commands and orchestrates the MSP430 lifecycle. |
| `usb_link` | 5 | Detects a USB host, finds a valid protocol header, and attempts to claim the session. |
| `tcp_link` | 5 | Starts once, waits for a Wi-Fi connection, then accepts TCP clients and attempts to claim the session. |
| `provisioning` | 5 | Persistent Wi-Fi owner. Applies boot policy, provisions or reconnects, publishes connectivity, and configures power save/TWT. |
| `packet_tx` | 4 | Sole writer to USB or TCP. Serializes control responses and acquisition packets. |

The threads exchange data and synchronize through these channels:

| Communication mechanism | Producer | Consumer | Why it is needed |
|---|---|---|---|
| Protocol session queue | `usb_link`, `tcp_link` | `protocol` | Hands a newly claimed USB or TCP session to the sole command reader without letting the link tasks process commands themselves. |
| Acquisition command queue | `protocol`, `packet_tx` | `acquisition` | Serializes all MSP430 reset, configuration, start, stop, and cleanup operations in the only task allowed to own acquisition hardware. |
| Control-response queue | `protocol`, `usb_link`, `tcp_link` | `packet_tx` | Funnels acknowledgements, errors, and `BUSY` replies through the sole transport writer so packets cannot interleave. |
| DMA frame pool and counting semaphores | `acquisition` | `packet_tx` | Transfers ownership of completed frames without copying their payloads and applies bounded buffering when transmission is slower than acquisition. |
| Per-command binary semaphore | `acquisition` | Command submitter (`protocol` or `packet_tx`) | Returns the result of one acquisition command and keeps its request alive if the submitter times out before execution finishes. |
| Per-response task notification | `packet_tx` | Response submitter (`protocol`, `usb_link`, or `tcp_link`) | Returns the result of a synchronous control-packet transmission without requiring a separate response queue. |
| Task wake notifications | GPIO ISR and acquisition-command submitters; `acquisition` and control-response submitters | `acquisition`; `packet_tx` | Wakes an owner task after new work arrives; queues and frame state remain the authoritative record of that work. |
| Mutex-protected session state | `usb_link`, `tcp_link`, `protocol` | All transport, protocol, acquisition, and TX tasks | Enforces one active transport and uses a generation number to reject commands or frames belonging to an old session. |
| Mutex-protected acquisition state and status | `acquisition`, `packet_tx` | `protocol`, `packet_tx` | Publishes whether acquisition is active plus sticky errors and counters for status replies and safe TX decisions. |
| Provisioner event group and protected state | Wi-Fi event handlers, `protocol` | `provisioning`, `tcp_link`, `protocol` | Announces connection changes and coordinates credential updates, reconnection, mDNS, power saving, and when TCP may listen. |

`app_main()` performs initialization and starts these threads. It does not move
acquisition data.

Before normal threads start, `app_main()` checks for a committed MSP430 update
and runs it synchronously. Uploads arrive through the normal protocol task;
commit persists the request and creates a short-lived `msp430_reboot` task to
restart the ESP32 after 250 ms. USB/TCP application commands are unavailable
during the subsequent boot-time programming. Results and JTAG diagnostics are
stored in NVS for retrieval after normal startup. See
[MSP430 updates](msp430_update_guide.md) for the lifecycle and recovery limits.

## Acquisition data path

```mermaid
flowchart LR
    MSP[MSP430 acquisition] -->|DATA_READY rising edge| ISR[GPIO ISR]
    ISR -->|task notification| ACQ[acquisition thread]
    ACQ -->|SPI DMA transfer| SLOT[DMA frame slot]
    SLOT -->|READY ownership| TX[packet TX thread]
    TX -->|framed acquisition packet| LINK{Active session}
    LINK --> USB[USB CDC]
    LINK --> TCP[Wi-Fi TCP]
    USB --> HOST[PC host]
    TCP --> HOST
```

SPI DMA writes each complete acquisition payload directly into a frame slot.
The payload is not copied between the acquisition and packet-TX threads.

The default frame pool contains 64 slots. At 500 frames/s it holds 128 ms of
data and consumes 51,456 bytes for payload storage, plus small metadata and
allocator overhead. Slots move through these ownership states:

```text
FREE -> SPI -> READY -> TX -> FREE
```

If no free slot becomes available within 100 ms, acquisition stops and the
sticky `ACQ_BUFFER_OVERFLOW` status flag and overflow counter are set. Completed
frames still queued when the session is stopped are released and counted as
discarded frames.

## Control path

```mermaid
flowchart LR
    HOST[PC host] -->|framed command| TRANSPORT[USB or TCP transport]
    TRANSPORT -->|claim| SESSION[session manager]
    TRANSPORT -->|session queue| PROTO[protocol thread]
    PROTO -->|command queue| ACQ[acquisition thread / SPI]
    ACQ -.->|completion| PROTO
    PROTO -->|control-response queue| TX[packet TX thread]
    TX -->|framed response| TRANSPORT
    TRANSPORT -->|framed response| HOST
```

The protocol thread is the only active-link reader. The packet-TX thread is the
only writer, preventing control headers and RF payloads from interleaving. It
drains pending control responses before sending another ready acquisition
frame; an in-progress packet is never interrupted.

## USB and Wi-Fi session switching

USB and TCP listeners do not claim ownership merely because a cable is attached
or a socket connects. A listener waits for a valid protocol frame before it
attempts to claim the global session.

The first valid frame wins. A competing transport receives `BUSY`, and it does
not gain access to acquisition data.

To switch transports cleanly:

1. Stop acquisition on the current transport.
2. Send `CLOSE`.
3. Wait for its acknowledgement and allow the ESP32 to return the MSP430 to its
   safe configuration state.
4. Connect with the other transport and send its first command.

The USB cable may remain physically connected when switching to Wi-Fi. An idle
USB connection does not own the protocol session. If the USB application still
has an active session, a TCP client receives `BUSY` until USB closes or fails.

Session references include a generation counter. Queued frames from an older
session are rejected after ownership changes, preventing stale data from being
sent to the new host.

## Acquisition state machine and MSP430 handshake

The acquisition task is the only owner of MSP430 reset, DATA_READY, and
acquisition SPI. The protocol thread queues MSP430 commands to the acquisition
task and waits for their result before sending a success or error response to
the PC host.

```mermaid
stateDiagram-v2
    direction TB
    [*] --> RESET
    RESTARTING --> WAIT_CONFIG: handshake succeeds
    RESET --> WAIT_CONFIG: session opens / reset released
    RESET --> QUIESCENT: STOP_RX or cleanup
    WAIT_CONFIG --> CONFIGURING: 0xFA configuration received
    WAIT_CONFIG --> QUIESCENT: STOP_RX or cleanup
    CONFIGURING --> CONFIGURED: handshake succeeds
    CONFIGURING --> QUIESCENT: failure or cancellation
    CONFIGURED --> ACQUIRING: START_RX
    ACQUIRING --> CONFIGURED: internal DISABLE
    CONFIGURED --> QUIESCENT: STOP_RX or cleanup
    ACQUIRING --> QUIESCENT: STOP_RX or cleanup
    QUIESCENT --> ACQUIRING: START_RX with valid configuration
    QUIESCENT --> RESTARTING: new restart command
    RESTARTING --> QUIESCENT: handshake fails
    QUIESCENT --> RESET: session closes / MSP430 reset asserted
```

The main transitions are:

| Event | Result |
|---|---|
| Session opens | Reset the MSP430 for 10 ms, then wait for its configuration request. |
| `SET_ACQ_CONFIG` (`0xFA`) | Wait for DATA_READY, send the 804-byte configuration, and confirm DATA_READY returns low. |
| `START_RX` | Publish any frame received just before START, then publish subsequent frames normally. |
| Internal `DISABLE` | Stop publication; at most one completed frame may remain private. This is not a PC protocol command. |
| `STOP_RX` | Finish any active SPI transfer, stop acquisition, and discard private and queued frames. |
| Restart (`0xFB`) | Send the restart block and wait for the next configuration-request assertion. |
| Session closes or fails | Quiesce, restart if needed, assert reset, and release session ownership. |

`QUIESCENT` is a stable stopped state of the acquisition task. With a valid
configuration, `START_RX` can resume acquisition directly. A restart instead
sends the `0xFB` block, waits for the MSP430's next configuration request, and
then changes the state to `WAIT_CONFIG`. A failed restart returns to
`QUIESCENT` without retrying automatically. Session cleanup proceeds to
`RESET`; otherwise, another restart attempt requires a new command.

DATA_READY notifications only wake the task. The GPIO level and a rising-edge
counter determine whether an assertion is new, so a signal held high cannot
start duplicate transfers. A rising edge also proves that a short low pulse
occurred when the pulse was too brief to observe directly.

Each queued command has its own completion result and session reference. Timed
out or stale-session commands are cancelled without affecting later commands.
An SPI transfer already in progress is allowed to finish safely. Handshake waits
time out after two seconds; the complete queued command has an eight-second
limit.

The acquisition implementation is split by responsibility:

| File | Responsibility |
|---|---|
| `acquisition_thread.c` | Command queue, state transitions, scheduling loop, and task lifecycle. |
| `acquisition_handshake.c` | DATA_READY ISR, edge tracking, handshake waits, and MSP430 restart transfer. |
| `acquisition_frames.c` | SPI frame reception, pending-frame ownership, publication, and cleanup. |
| `acquisition_internal.h` | Private state and interfaces shared by those files. |

The legacy GUI sequence `STOP_RX -> SET_ACQ_CONFIG(0xFB) ->
SET_ACQ_CONFIG(0xFA) -> START_RX` remains supported.

Host regression tests and the physical-board verification matrix are documented
in [acquisition tests](../tests/acquisition/README.md).

## USB management

The native USB CDC link uses the ESP32-C6 USB Serial/JTAG peripheral. Power
management and CPU frequency scaling follow physical USB presence,
independently of protocol session ownership.

```mermaid
flowchart LR
    POLL[USB monitor cycle] --> LOCK[Hold sleep + CPU-max locks]
    LOCK -->|wait 10 ms| CHECK{Host present?}
    CHECK -->|yes| ACTIVE[USB available]
    CHECK -->|no| RELEASE[Release both locks]
    ACTIVE -->|brief missing indication| ACTIVE
    ACTIVE -->|missing for 100 ms| RELEASE[Release both locks]
    RELEASE -->|retry after 100 ms| POLL
```

| Mechanism | Purpose |
|---|---|
| `ESP_PM_NO_LIGHT_SLEEP` | Prevent light sleep from interrupting USB CDC. |
| `ESP_PM_CPU_FREQ_MAX` | Keep USB clocks stable while a host is attached. |
| 100 ms disconnect filter | Ignore brief false disconnect indications from USB SOF monitoring. |

Both locks are acquired before checking USB presence and retained while a host
is attached. They are released when no host is found, after applying the 100 ms
filter to a previously active connection. Holding the maximum-frequency lock
increases power consumption while USB is attached, but avoids corrupted command
bytes and transient disconnects observed when the tested ESP32-C6 rev0.2 board
used dynamic frequency scaling down to 10 MHz.

An attached USB cable does not claim the protocol session. USB and Wi-Fi
session ownership continues to follow the first valid command as described
above.

See [ESP32-to-PC protocol](esp32_pc_protocol.md), [ESP32-to-MSP430 acquisition protocol](msp430_acq_protocol.md),
and [Wi-Fi provisioning](wifi_provisioning_guide.md) for the corresponding wire formats and
startup workflow.

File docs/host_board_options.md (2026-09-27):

# Host board options

WULPUS Pro Max has three host configurations. The
[WiFi host PCB](../hw/wulpus_wifi_host_pcb) is recommended for normal
use because it integrates communication, power delivery, and programming in one
board. The other options are intended for development or compatibility with
legacy setups. The nRF52 BLE option may also suit applications that need even
lower power consumption than the WiFi host solution, but it is unsupported,
is not recommended for new setups, and requires additional integration work.

| Capability | WiFi host PCB | Standalone Seeed Studio XIAO ESP32-C6 | nRF52 BLE solution |
|---|---|---|---|
| Status | Primary and recommended | Development alternative | Legacy, unsupported; not recommended for new setups |
| PC connection | USB CDC or WiFi/TCP | USB CDC or WiFi/TCP | BLE through an nRF52840 USB dongle |
| Acquisition PCB interface | Integrated WULPUS PRO connector | Manual Dupont wiring | Manual Dupont wiring to an nRF52832 DK |
| Powers the Acquisition PCB | Yes | No; external lab supplies are required | No; external power is required |
| Programs the MSP430 | Yes, through the updater GUI | No; JTAG signals are not exposed on the Acquisition PCB Dupont connectors | No; use an external programmer |
| Battery charging | Supported via USB, with integrated battery protection | Not provided for the Acquisition PCB | Not provided |
| Additional hardware | One data-capable USB-C cable | Data-capable USB-C cable, Dupont wires, and lab power supplies | nRF52832 DK, nRF52840 USB dongle, wiring, and external power |

## WiFi host PCB

This option provides the simplest setup. A single USB-C connection can power
the system, provide USB communication, flash the ESP32, and then program the
MSP430 through the updater GUI. WiFi can be used for wireless control and data
transfer after provisioning, with acquisition PRFs of up to 500 Hz over
Wi-Fi/TCP or native USB CDC. The platform can also be powered by an external
Adafruit battery with a standard JST connector, with USB battery charging and
integrated battery protection.

## Standalone Seeed Studio XIAO ESP32-C6

The standalone XIAO runs the same ESP32 firmware and supports the same USB CDC
and WiFi/TCP protocol. It must be wired manually to the Acquisition PCB, and all
Acquisition PCB power domains must be supplied externally. It cannot program
the MSP430, so the Acquisition PCB must already contain compatible MSP430
firmware. See the [board setup and pin mapping](../fw/esp32/docs/development_guide.md#supported-boards).

## nRF52 BLE solution

The legacy BLE setup uses an nRF52832 DK as the Acquisition PCB host and an
nRF52840 USB dongle at the PC. It may suit applications with stricter power
requirements than the WiFi host solution, but it is unsupported and is not
recommended for new setups. Additional integration work is required, including
manual wiring, external power, and a separate programmer for the MSP430. It
does not provide the integrated USB, WiFi, power, or MSP430-programming workflow
of the WiFi host PCB. See the [legacy nRF52 firmware instructions](../fw/nrf52/README.md).

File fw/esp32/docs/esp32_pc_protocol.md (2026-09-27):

# ESP32-to-PC protocol

The ESP32 exposes the same ordered byte-stream protocol over Wi-Fi/TCP and the
ESP32-C6 native USB Serial/JTAG CDC interface. Packets, command IDs, payloads,
and acknowledgements are transport-independent.

## Contents

- [Transports](#transports)
- [Packet format](#packet-format)
- [Commands](#commands)
- [Persistent device configuration](#persistent-device-configuration)
- [Acknowledgement model](#acknowledgement-model)
- [Acquisition frame](#acquisition-frame)
- [Typical acquisition session](#typical-acquisition-session)
- [Runtime status](#runtime-status)
- [Clearing status](#clearing-status)
- [Firmware information](#firmware-information)
- [MSP430 firmware update commands](#msp430-firmware-update-commands)

## Transports

| Transport | Endpoint | Notes |
|---|---|---|
| Wi-Fi TCP | TCP port 2121 by default | Discovered through the `_wulpus_pro._tcp` mDNS service after Wi-Fi obtains an IP address. |
| USB CDC | ESP32-C6 USB Serial/JTAG COM port | Baud-rate settings do not control USB line speed. The port must not be open in another GUI, terminal, or monitor. |

Only one transport owns a protocol session at a time. See
[Firmware architecture](firmware_architecture.md#usb-and-wi-fi-session-switching) for
arbitration and switching.

## Packet format

Every message is one packed nine-byte header followed immediately by
`data_length` payload bytes:

| Offset | Size (bytes) | Field | Encoding |
|---:|---:|---|---|
| 0 | 6 | `magic` | ASCII `wulpus` (`77 75 6c 70 75 73`). |
| 6 | 1 | `command` | Command ID from the table below. |
| 7 | 2 | `data_length` | Unsigned little-endian payload length, 0–65535. |
| 9 | variable | `payload` | Command-specific bytes. |

Construct a packet by concatenating the packed header and the payload. Multi-byte
fields use little-endian byte order.

TCP and USB may split or combine packets arbitrarily. A receiver must accumulate
bytes until the complete header and declared payload are available; one socket
read or serial read is not guaranteed to equal one protocol packet.

Before a session is claimed, each listener scans the stream for the `wulpus`
magic. This also recovers from boot text or stale serial bytes. During an active
session, a malformed header or oversized command payload is a protocol error
and ends the session rather than silently resynchronizing in the middle of a
packet.

## Commands

| ID | Name | Direction | Request payload | Responses and effect |
|---:|---|---|---|---|
| `0x57` | `SET_ACQ_CONFIG` | PC -> ESP | MSP430 acquisition configuration package, at most 804 bytes | Empty acknowledgement after DATA_READY and successful SPI transfer; `ERROR` on timeout/transfer failure, `BUSY` while an update is pending. Does not confirm MSP430 application of the configuration. |
| `0x58` | `GET_DATA` | ESP -> PC | 804-byte RF payload | Asynchronous acquisition frame emitted while RX is enabled. It is not a host polling request. |
| `0x59` | `PING` | PC -> ESP | Empty | Empty `PING` acknowledgement, followed by `PONG` containing ASCII `pong`. |
| `0x5A` | `PONG` | ESP -> PC | ASCII `pong` | Second response to `PING`. |
| `0x5B` | `RESET` | PC -> ESP | Empty | Stops acquisition, shuts down/resets MSP430, queues an empty acknowledgement, then restarts ESP32. `BUSY` while an update is pending. Delivery before restart is not guaranteed. |
| `0x63` | `RESET_MSP` | PC -> ESP | Empty | If acquisition and update are inactive, pulses MSP430 reset and acknowledges after its boot delay; otherwise `BUSY`. Keeps the session open. |
| `0x5C` | `CLOSE` | PC -> ESP | Empty | Acquisition is stopped, then an empty `CLOSE` acknowledgement is sent. The session proceeds through common cleanup and releases ownership. |
| `0x5D` | `START_RX` | PC -> ESP | Empty | Empty acknowledgement after enabling acquisition forwarding; `BUSY` while an update is pending. |
| `0x5E` | `STOP_RX` | PC -> ESP | Empty | Acquisition and queued session frames are stopped/discarded before the empty `STOP_RX` acknowledgement is sent. The protocol session remains open. |
| `0x5F` | `BUSY` | ESP -> PC | Empty | Another transport owns the session, `RESET_MSP` is requested during acquisition, or acquisition configuration/start/reset conflicts with a pending update. |
| `0x60` | `GET_STATUS` | PC -> ESP | Empty | Empty `GET_STATUS` acknowledgement followed by one `STATUS` packet. |
| `0x61` | `STATUS` | ESP -> PC | 40-byte versioned status payload | Runtime errors, counters, and frame-pool occupancy. |
| `0x62` | `CLEAR_STATUS` | PC -> ESP | Empty or five-byte clear request | Requested flags/counters are cleared before the empty `CLEAR_STATUS` acknowledgement is sent. |
| `0x64` | `GET_DEVICE_CONFIG` | PC -> ESP | Empty | Acknowledgement followed by `DEVICE_CONFIG`. |
| `0x65` | `DEVICE_CONFIG` | ESP -> PC | 16-byte versioned configuration | Complete non-secret persistent boot configuration. |
| `0x66` | `SET_DEVICE_CONFIG` | PC -> ESP | Complete 16-byte configuration | Atomically replaces the configuration; takes effect after reboot. |
| `0x67` | `GET_WIFI_STATUS` | PC -> ESP | Empty | Acknowledgement followed by `WIFI_STATUS`. |
| `0x68` | `WIFI_STATUS` | ESP -> PC | 12-byte versioned status | State, credential presence, RSSI, and IP; never SSID/password. |
| `0x69` | `SET_WIFI_CREDENTIALS` | PC -> ESP | Header followed by SSID/password | Replaces credentials; takes effect after reboot. |
| `0x6A` | `CLEAR_WIFI_CREDENTIALS` | PC -> ESP | Empty | Clears credentials; takes effect after reboot. |
| `0x6B` | `ERROR` | ESP -> PC | Failed command and ESP error | Command validation, configuration transfer, persistent setter, or update operation failed. |
| `0x6C` | `MSP_UPDATE_BEGIN` | PC -> ESP | 12-byte upload descriptor | Empty acknowledgement after staging setup; `ERROR` on rejection. |
| `0x6D` | `MSP_UPDATE_DATA` | PC -> ESP | 12-byte chunk header + data | 8-byte offset/sequence acknowledgement, or `ERROR`. |
| `0x6E` | `MSP_UPDATE_COMMIT` | PC -> ESP | Empty | Acknowledges persisted update scheduling; ESP32 reboots to program MSP430. |
| `0x6F` | `MSP_UPDATE_ABORT` | PC -> ESP | Empty | Acknowledges abort request; use before commit. |
| `0x70` | `MSP_UPDATE_GET_STATUS` | PC -> ESP | Empty | Empty acknowledgement followed by `MSP_UPDATE_STATUS`. |
| `0x71` | `MSP_UPDATE_STATUS` | ESP -> PC | 28-byte update status | Separate from acquisition `STATUS`. |
| `0x72` | `MSP_UPDATE_GET_DIAGNOSTICS` | PC -> ESP | Empty | Direct `MSP_UPDATE_DIAGNOSTICS` response, without a separate empty acknowledgement. |
| `0x73` | `MSP_UPDATE_DIAGNOSTICS` | ESP -> PC | 16-byte diagnostics | Last JTAG identification diagnostics. |
| `0x74` | `GET_FIRMWARE_INFO` | PC -> ESP | Empty | Empty acknowledgement followed by `FIRMWARE_INFO`. |
| `0x75` | `FIRMWARE_INFO` | ESP -> PC | 72-byte versioned firmware information | ESP32 build version and the MSP430 version detected during configuration, with reserved Git build metadata. |

Command values not explicitly listed above are invalid in the current protocol.
Commands documented as ESP32-to-PC should not be sent by a host.

## Persistent device configuration

The persistent device configuration controls how the ESP32 initializes Wi-Fi
and its power-saving features at startup. It is stored in non-volatile memory,
survives power cycles, and is applied after the ESP32 restarts.

`DEVICE_CONFIG` is the following packed 16-byte structure:

| Offset | Size (bytes) | Field | Allowed values | Default | Meaning |
|---:|---:|---|---|---|---|
| 0 | 1 | `version` | `1` | `1` | Structure version. |
| 1 | 1 | `size` | `16` | `16` | Complete structure size in bytes. |
| 2 | 1 | `wifi_enabled_at_boot` | `0` or `1` | `1` | Start Wi-Fi during boot. |
| 3 | 1 | `auto_provision` | `0` or `1` | `1` | Start provisioning when Wi-Fi is enabled and no credentials are saved. |
| 4 | 1 | `wifi_power_save_mode` | `0`: none; `1`: minimum modem; `2`: maximum modem | `2` | Select the Wi-Fi power-save mode. |
| 5 | 1 | `twt_enabled` | `0` or `1` | `0` | Enable Target Wake Time when supported. |
| 6 | 10 | `reserved` | All bytes zero | All bytes zero | Reserved for future versions. |

`SET_DEVICE_CONFIG` replaces the complete structure. A client should read the
current configuration, modify the required fields, write the complete structure,
and issue `RESET` to apply it.

`auto_provision` is consulted only when Wi-Fi is enabled at boot and no saved
credentials exist. It remains persistent after provisioning, and saved
credentials take priority.

The `SET_WIFI_CREDENTIALS` payload has this variable-length layout:

| Offset | Size (bytes) | Field | Requirements |
|---:|---:|---|---|
| 0 | 1 | `version` | Must be `1`. |
| 1 | 1 | `ssid_length` | 1–32 bytes. |
| 2 | 1 | `password_length` | 0–64 bytes. |
| 3 | 1 | `reserved` | Must be zero. |
| 4 | `ssid_length` | `ssid` | Raw SSID bytes. |
| 4 + `ssid_length` | `password_length` | `password` | Raw password bytes. |

Credentials can be replaced or cleared but never read through this protocol.

## Acknowledgement model

Most PC commands receive an empty packet with the same command ID as their
acknowledgement. The acknowledgement indicates that the command was accepted by
the protocol task. `SET_ACQ_CONFIG` now acknowledges after SPI transfer success,
but there is no separate MSP430 application-level acceptance response.
`MSP_UPDATE_COMMIT` acknowledges scheduling, not programming completion.
Use `GET_STATUS` for acquisition SPI/buffer errors and `MSP_UPDATE_GET_STATUS`
for the separate persisted update result. `PING` establishes ESP32 protocol
responsiveness, not MSP430 health.

Acknowledgements are ordered with acquisition data by the sole packet-TX
thread. Because RF frames are asynchronous, a `GET_DATA` packet may already be
buffered when the host begins waiting for a command response. The host parser
must consume complete packets and continue until it finds the expected command
ID. It must never interpret arbitrary bytes following an RF payload as a
response header.

Special response sequences are:

```text
PING        -> PING acknowledgement -> PONG("pong")
GET_STATUS  -> GET_STATUS acknowledgement -> STATUS(payload)
CLEAR_STATUS -> CLEAR_STATUS acknowledgement after clearing
RESET_MSP   -> RESET_MSP acknowledgement after MSP430 restart, or BUSY
CLOSE       -> CLOSE acknowledgement after stopping RX
```

## Acquisition frame

`GET_DATA` has an 804-byte payload:

| Offset | Size (bytes) | Field | Encoding |
|---:|---:|---|---|
| 0 | 1 | `frame_marker` | `0xFF` from MSP430. |
| 1 | 1 | `tx_rx_id` | Active TX/RX configuration index. |
| 2 | 2 | `acquisition_number` | Unsigned little-endian 16-bit sequence number. |
| 4 | 800 | `samples` | 400 little-endian signed 16-bit samples. |

Including the outer header, one acquisition packet occupies 813 application
bytes. At 500 FPS this requires 406,500 bytes/s (3.252 Mbit/s) before USB or TCP
transport overhead.

The acquisition number is a wrapping sequence value, not an array index or a
reliable indication of progress within a newly requested acquisition. Detect
gaps by comparing consecutive values with modulo-65536 arithmetic.

## Typical acquisition session

```text
PC                                      ESP32 / MSP430
--                                      --------------
connect/open CDC
PING ---------------------------------> claim session, release MSP430 reset
     <------------------------------- PING acknowledgement
     <------------------------------- PONG "pong"
SET_ACQ_CONFIG(package) --------------> transfer configuration to MSP430
     <------------------------------- SET_ACQ_CONFIG acknowledgement
CLEAR_STATUS(mask, counters=1) -------> clear diagnostics
     <------------------------------- CLEAR_STATUS acknowledgement
START_RX -----------------------------> enable forwarding
     <------------------------------- START_RX acknowledgement
     <------------------------------- GET_DATA frame 0
     <------------------------------- GET_DATA frame 1
     <------------------------------- ...
STOP_RX ------------------------------> stop and discard queued session frames
     <------------------------------- STOP_RX acknowledgement
GET_STATUS ---------------------------> snapshot diagnostics
     <------------------------------- GET_STATUS acknowledgement
     <------------------------------- STATUS payload
CLOSE --------------------------------> stop and clean up MSP430/session
     <------------------------------- CLOSE acknowledgement
```

## Runtime status

The version-1 `STATUS` payload is a packed 40-byte little-endian structure:

| Offset | Size (bytes) | Field | Meaning |
|---:|---:|---|---|
| 0 | 1 | `version` | Status schema version; currently 1. |
| 1 | 1 | `size` | Total payload size; currently 40. |
| 2 | 2 | `reserved` | Reserved, currently zero. |
| 4 | 4 | `error_flags` | Sticky error bit mask. |
| 8 | 4 | `buffer_overflow_count` | Times acquisition could not obtain a free frame slot. |
| 12 | 4 | `data_ready_count` | DATA_READY edges serviced by the acquisition thread. |
| 16 | 4 | `completed_spi_count` | Successful acquisition SPI transactions. |
| 20 | 4 | `transmitted_frame_count` | RF frames successfully written to the active link. |
| 24 | 4 | `discarded_frame_count` | Completed frames released without transmission, normally during stop/session cleanup or generation changes. |
| 28 | 4 | `spi_error_count` | Failed or timed-out SPI transfers. |
| 32 | 4 | `link_error_count` | Packet-write/link failures. |
| 36 | 2 | `current_buffer_usage` | Frame slots currently owned by SPI, READY, or TX. |
| 38 | 2 | `maximum_buffer_usage` | High-water mark since initialization or counter reset. |

### Error flags

| Bit | Mask | Name | Meaning |
|---:|---:|---|---|
| 0 | `0x00000001` | `ACQ_BUFFER_OVERFLOW` | No free DMA frame slot became available within the acquisition wait. Acquisition is stopped. |
| 1 | `0x00000002` | `DATA_READY_OVERFLOW` | Reserved by the current status schema for lost/excess DATA_READY events. |
| 2 | `0x00000004` | `SPI_TIMEOUT` | MSP430 edge or SPI shutdown/transfer timing failed. |
| 3 | `0x00000008` | `SPI_FAILURE` | Non-timeout SPI operation failed. |
| 4 | `0x00000010` | `LINK_TIMEOUT` | A packet could not be written within the link timeout. |
| 5 | `0x00000020` | `LINK_DISCONNECTED` | Reserved for explicit link-disconnect reporting. |
| 6 | `0x00000040` | `PROTOCOL` | Invalid active-session header or payload length. |

Error flags are sticky until `CLEAR_STATUS` or reboot. Counters are unsigned
32-bit values and are not automatically reset at the beginning of a host
acquisition unless the host requests it.

## Clearing status

An empty `CLEAR_STATUS` request clears all error bits but preserves counters.
The optional five-byte request payload is:

| Offset | Size (bytes) | Field | Meaning |
|---:|---:|---|---|
| 0 | 4 | `error_mask` | Little-endian bit mask of sticky errors to clear. |
| 4 | 1 | `clear_counters` | Nonzero clears all diagnostic counters and resets the frame-pool high-water mark. |

For example, an `error_mask` of `0xFFFFFFFF` with `clear_counters` set to `1`
clears every defined error flag and all counters.

## Firmware information

`GET_FIRMWARE_INFO` receives an empty acknowledgement followed by a
`FIRMWARE_INFO` response. The version-1 response payload is the following packed
72-byte structure:

| Offset | Size (bytes) | Field | Meaning |
|---:|---:|---|---|
| 0 | 1 | `version` | Firmware-information schema version; currently `1`. |
| 1 | 1 | `size` | Total payload size; currently `72`. |
| 2 | 1 | `flags` | Bit 0: MSP430 version valid; bit 1: ESP32 source dirty; bit 2: MSP430 source dirty; bits 3-7 reserved. Dirty bits are reserved and currently remain clear. |
| 3 | 1 | `reserved` | Reserved, currently zero. |
| 4 | 1 | `msp_major` | MSP430 semantic-version major component. |
| 5 | 1 | `msp_minor` | MSP430 semantic-version minor component. |
| 6 | 1 | `msp_patch` | MSP430 semantic-version patch component. |
| 7 | 1 | `reserved_2` | Reserved, currently zero. |
| 8 | 32 | `esp_version` | NUL-terminated ESP-IDF application-version string. |
| 40 | 13 | `esp_git_hash` | NUL-terminated Git hash of up to 12 hexadecimal characters; reserved and currently empty. |
| 53 | 13 | `msp_git_hash` | NUL-terminated Git hash of up to 12 hexadecimal characters; reserved and currently empty. |
| 66 | 6 | `reserved_3` | Reserved, currently zero. |

The MSP430 version becomes available after a successful acquisition-
configuration SPI transfer. Until then, or when using older MSP430 firmware,
flag bit 0 is clear and the MSP430 version fields must be ignored.
Git-hash generation and scoped dirty-source detection are not yet integrated
into the firmware builds, so both hash fields are empty and both dirty bits are
currently clear.

## MSP430 firmware update commands

The command table above includes the MSP430 update command IDs. See the
[MSP430 firmware update protocol](msp430_update_protocol.md) for upload payloads,
acknowledgements, status values, and diagnostics.

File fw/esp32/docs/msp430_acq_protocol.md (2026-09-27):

# ESP32-to-MSP430 acquisition protocol

The ESP32 is the SPI master and the MSP430 acquisition controller is
the SPI slave. The interface uses fixed-length, full-duplex transactions: data
from the ESP32 configures or restarts the MSP430 while data from the MSP430
contains an acquisition frame when one is available.

## Contents

- [Electrical and SPI settings](#electrical-and-spi-settings)
- [Transaction phases](#transaction-phases)
- [Configuration package](#configuration-package)
- [RF acquisition payload](#rf-acquisition-payload)
- [Current constraints](#current-constraints)

## Electrical and SPI settings

| Property | Value |
|---|---|
| SPI role | ESP32 master, MSP430 slave |
| Clock | 8 MHz by default (`CONFIG_WP_SPI_CLOCK_SPEED`) |
| Mode | SPI mode 1 |
| Bit order | MSB first |
| Chip select | Active low, hardware-controlled by the ESP32 SPI driver |
| Transaction length | 804 bytes |
| Flow-control signal | Active-high `DATA_READY` from MSP430 to ESP32 |
| MSP430 reset | Active-low, open-drain `MSP_RST_N` from ESP32 |

The MSP430 raises `DATA_READY` only after its SPI DMA is prepared. The ESP32
detects the rising edge and performs one 804-byte transaction. The MSP430 lowers
`DATA_READY` when its receive DMA completes.

## Transaction phases

### Configuration phase

After the ESP32 releases `MSP_RST_N`, the MSP430 initializes its peripherals,
disables acquisition power paths, and requests a configuration transfer by
raising `DATA_READY`.

The ESP32 transmits an 804-byte block whose meaningful prefix is the
configuration package described below. The remainder is zero padding. The
MSP430 examines byte 0; it accepts the package only when that byte is `0xFA`.
Invalid packages cause it to request another configuration transaction.

### Acquisition phase

After applying a valid configuration, the MSP430 performs acquisitions at the
configured measurement period. When an acquisition completes, it prepares the
804-byte RF frame, raises `DATA_READY`, and waits for the ESP32 SPI transaction.

During that full-duplex transaction:

- MSP430 to ESP32 carries the RF frame.
- ESP32 to MSP430 is normally zero-filled.
- If ESP32 byte 0 is `0xFB`, the MSP430 exits the acquisition loop after the
  transfer and returns to the configuration phase.

This restart-on-next-transfer behavior allows a graceful shutdown: the ESP32
sends an 804-byte block beginning with `0xFB`, waits for `DATA_READY` to fall,
and then waits for the next configuration request before asserting reset.

## Configuration package

All multibyte values are little-endian. The host sends a 105-byte configuration
package, and the ESP32 zero-pads it to the fixed 804-byte SPI transaction.

### Fixed prefix

| Offset | Size (bytes) | Field | Meaning |
|---:|---:|---|---|
| 0 | 1 | `start_byte` | `0xFA` identifies a configuration package. |
| 1 | 2 | `dcdc_turnon` | Slow-timer count for enabling the HV DC-DC before acquisition. Generated as `floor(microseconds * 65535 / 2000000)`. It must be lower than `meas_period` so the DC-DC event occurs before acquisition in the timer sequence. |
| 3 | 2 | `meas_period` | Slow-timer acquisition-period count, using the same approximately 32.768 kHz conversion. A 2000 us period requests 500 FPS. |
| 5 | 4 | `trans_freq` | Transducer frequency in hertz. Present in the package but currently reserved/not used by MSP430 firmware. |
| 9 | 4 | `pulse_freq` | Pulse-generator frequency in hertz. |
| 13 | 1 | `num_pulses` | Number of excitation pulses, 0–30 in the host configuration model. |
| 14 | 2 | `oversampling_rate` | SDHS oversampling selector; see the table below. |
| 16 | 2 | `sample_size_bytes` | Number of sample bytes, generated as `2 * num_samples`. The current ESP transport and frame format are fixed at 800 sample bytes (400 samples). |
| 18 | 1 | `rx_gain` | MSP430 PGA gain register code. |
| 19 | 1 | `enable_envelope_detector` | `0` disables and `1` enables the hardware envelope detector. |
| 20 | 1 | `tx_rx_config_count` | Number of TX/RX mask pairs that follow; maximum 16. |

### TX/RX configuration array

Starting at offset 21, each configuration occupies four bytes:

| Relative offset | Size (bytes) | Field | Meaning |
|---:|---:|---|---|
| `4*i + 0` | 2 | `tx_mask[i]` | Little-endian 16-bit transmit-channel mask. |
| `4*i + 2` | 2 | `rx_mask[i]` | Little-endian 16-bit receive-channel mask. |

The MSP430 cycles `tx_rx_id` from zero through
`tx_rx_config_count - 1`, then wraps to zero. A zero TX mask is useful for
receive-only throughput testing because it suppresses excitation pulses.

### Advanced timing and VGA fields

The advanced section starts at:

```text
advanced_offset = 21 + 4 * tx_rx_config_count
```

| Relative offset | Size (bytes) | Field | Host conversion and meaning |
|---:|---:|---|---|
| 0 | 2 | `start_hvmuxrx` | HV-MUX receive timing; `floor(us * 8)`. |
| 2 | 2 | `start_ppg` | Pulse-generator start timing; `floor(us * 5)`. |
| 4 | 2 | `turnon_adc` | ADC turn-on timing; `floor(us * 5)`. |
| 6 | 2 | `start_pgainbias` | PGA input-bias start timing; `floor(us * 5)`. |
| 8 | 2 | `start_adcsampl` | ADC sampling start timing; `floor(us * 5)`. |
| 10 | 2 | `restart_capt` | Capture-restart timing; `floor(us * 5 / 16)`. |
| 12 | 2 | `capt_timeout` | Capture timeout; `floor(us * 5 / 4)`. |
| 14 | 2 | `vga_rc_precharge_cycles` | VGA RC-network precharge duration in MSP430 delay cycles. Zero disables precharge. |
| 16 | 2 | `vga_slope_code` | Digital-potentiometer code for time-gain slope. Values 0–255 select a slope; 256 selects fixed-gain mode. |

The complete meaningful length is `39 + 4 * tx_rx_config_count` bytes. At the
maximum 16 configurations this is 103 bytes; the host package is padded to 105
bytes and the ESP32 SPI block to 804 bytes.

### Oversampling and sampling frequency

The host maps the SDHS oversampling selector to sample rate as follows:

| Register value | Oversampling ratio | Sampling frequency |
|---:|---:|---:|
| 0 | 10 | 8 MHz |
| 1 | 20 | 4 MHz |
| 2 | 40 | 2 MHz |
| 3 | 80 | 1 MHz |
| 4 | 160 | 500 kHz |

### RX gain

`rx_gain` is a hardware register code rather than a signed dB number. Supported
gain settings map to register codes 17–63; clients must use the MSP430 PGA gain
mapping rather than derive this byte directly from a dB value.

## RF acquisition payload

Every MSP430-to-ESP32 acquisition transfer is 804 bytes:

| Offset | Size (bytes) | Field | Meaning |
|---:|---:|---|---|
| 0 | 1 | `frame_marker` | `0xFF` identifies the beginning of an RF frame. |
| 1 | 1 | `tx_rx_id` | Index of the TX/RX configuration used for this frame. |
| 2 | 2 | `acquisition_number` | Little-endian unsigned 16-bit sequence number; increments after each successful acquisition and wraps at 65535. It resets when the MSP430 returns to its outer configuration loop. |
| 4 | 800 | `samples` | 400 little-endian signed 16-bit ADC samples. |

The ESP32 currently forwards all 804 bytes unchanged as the payload of a PC
`GET_DATA` packet. The host should use modulo-65536 sequence arithmetic when
detecting missing frames.

## Current constraints

- Host `PING` is answered by the ESP32; it is not an MSP430 health check.
  `SET_ACQ_CONFIG` is acknowledged after SPI transfer success and observation
  of DATA_READY low, without a separate MSP430 response validating the fields.
- ESP frame storage and the PC decoder are configured for a fixed 804-byte RF
  payload, corresponding to 400 samples. Although the configuration model
  exposes other sample counts, they require coordinated changes to the MSP430,
  ESP32 `CONFIG_WP_DATA_RX_LENGTH`, and host decoder.
- The MSP430 has one RF transfer buffer; it waits for the ESP32 transaction
  before advancing, so prompt servicing of `DATA_READY` is required.

See [Firmware architecture](firmware_architecture.md) for buffering and task ownership,
and [ESP32-to-PC protocol](esp32_pc_protocol.md) for the outer framing applied by the
ESP32.

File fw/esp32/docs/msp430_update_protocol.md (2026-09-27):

# MSP430 firmware update protocol

This protocol extends the [ESP32-to-PC protocol](esp32_pc_protocol.md) with commands
for staging an MSP430 image on the ESP32, programming the MSP430 after reboot,
and retrieving the saved result. It is intended for firmware and host-client
developers; users should follow the
[firmware update guide](../../../docs/firmware_update_guide.md).

## Contents

- [Upload messages](#upload-messages)
- [Upload sequence](#upload-sequence)
- [Update status](#update-status)
- [Update diagnostics](#update-diagnostics)
- [Complete command sequence](#complete-command-sequence)

All fields are packed and little-endian. Requests use the standard nine-byte
ESP32-to-PC packet header, and the maximum request payload is 804 bytes.

## Upload messages

| Command | Direction | Message | Field order (byte widths) |
|---|---|---|---|
| `MSP_UPDATE_BEGIN` (`0x6C`) | PC → ESP | Upload request | version (1, value 1), flags (1, send 0), reserved (2, zero), image_size (4), image_crc32 (4) |
| `MSP_UPDATE_BEGIN` (`0x6C`) | ESP → PC | Acknowledgement | Empty payload |
| `MSP_UPDATE_DATA` (`0x6D`) | PC → ESP | Chunk upload | offset (4), sequence (2), data_length (2), data_crc32 (4), data (1–792) |
| `MSP_UPDATE_DATA` (`0x6D`) | ESP → PC | Chunk acknowledgement | next_offset (4), accepted_sequence (2), reserved (2, zero) |

## Upload sequence

1. **Start the upload with `MSP_UPDATE_BEGIN`.**
   - Stop acquisition before sending this command and keep it stopped throughout
     the upload.
   - The ESP32 must have an available staging partition.
   - The CRC covers the complete staged container, including its header and
     section table.
2. **Transfer the image with repeated `MSP_UPDATE_DATA` commands.**
   - Each command carries one chunk and a CRC covering that chunk's data.
   - The offset must equal the number of bytes already accepted, which enforces
     chunk order.
   - The acknowledgement returns the accepted sequence value and the offset
     required for the next chunk.
3. **Finish the upload with `MSP_UPDATE_COMMIT`.**
   - The ESP32 accepts this command only after every image byte has been received.
   - This command blocks new acquisition and schedules an ESP32 reboot.
   - After reboot, the ESP32 validates the complete image and programs the
     MSP430.

See the [updater implementation](msp430_update_guide.md) for the image layout
and recovery limits.

## Update status

The 28-byte `MSP_UPDATE_STATUS` payload reports upload and programming progress:

| Offset | Size (bytes) | Field |
|---:|---:|---|
| 0 | 1 | version (1) |
| 1 | 1 | state |
| 2 | 2 | flags; bit 0 = boot update pending |
| 4 | 4 | received_bytes |
| 8 | 4 | total_bytes (container size) |
| 12 | 4 | processed_bytes (section data in current write/verify pass) |
| 16 | 4 | current_address |
| 20 | 4 | target_device_id (expected descriptor value `0x8317`) |
| 24 | 4 | error (signed ESP error code) |

The `state` field reports the current or final stage of the MSP430 firmware
update. Its numeric values are defined below:

| Value | State | Meaning |
|---:|---|---|
| 0 | `IDLE` | No update is active. |
| 1 | `RECEIVING` | The ESP32 is receiving image chunks. |
| 2 | `READY` | The complete image has been received and can be committed. |
| 3 | `VALIDATING` | The ESP32 is validating the staged image. |
| 4 | `PROGRAMMING` | The ESP32 is writing firmware to the MSP430. |
| 5 | `VERIFYING` | The ESP32 is verifying the programmed MSP430 memory. |
| 6 | `RESETTING` | Defined by the protocol but currently unused. |
| 7 | `WAITING_FOR_BOOT` | Defined by the protocol but currently unused. |
| 8 | `COMPLETE` | Programming and verification completed successfully. |
| 9 | `FAILED` | The update failed; inspect `error` and diagnostics. |
| 10 | `ABORTED` | The staged update was aborted. |

`processed_bytes` restarts from zero for verification and excludes container
metadata, so it is not directly comparable to `total_bytes`.

## Update diagnostics

The 16-byte `MSP_UPDATE_DIAGNOSTICS` response contains identifiers and control
values captured during the most recent MSP430 programming attempt:

| Offset | Size (bytes) | Field | Meaning |
|---:|---:|---|---|
| 0 | 1 | `version` | Diagnostics format version; currently `1`. |
| 1 | 1 | `stage` | Furthest diagnostic stage reached. |
| 2 | 2 | `jtag_id` | JTAG interface identifier. |
| 4 | 2 | `core_id` | MSP430 core identifier. |
| 6 | 2 | `control_signal` | Captured JTAG control-signal value. |
| 8 | 4 | `descriptor_pointer` | Address of the MSP430 device descriptor. |
| 12 | 2 | `quick_device_id` | Device identifier read through the quick-memory path. |
| 14 | 2 | `direct_device_id` | Device identifier read directly from memory. |

The `stage` field indicates how far identification progressed:

| Value | Stage | Current implementation |
|---:|---|---|
| 0 | Not started | Used |
| 1 | JTAG entry | Used |
| 2 | Core ID | Defined but not currently reported |
| 3 | Descriptor pointer | Defined but not currently reported |
| 4 | Synchronization | Defined but not currently reported |
| 5 | Device-memory read | Used |
| 6 | Device validated | Used |

`MSP_UPDATE_GET_DIAGNOSTICS` reads the stored result; it does not start a JTAG
operation.

## Complete command sequence

```text
MSP_UPDATE_BEGIN -> empty acknowledgement
MSP_UPDATE_DATA  -> next offset / accepted sequence (repeat per chunk)
MSP_UPDATE_COMMIT -> empty acknowledgement -> ESP32 reboot
                   validation / JTAG write / verification / normal startup
reconnect
MSP_UPDATE_GET_STATUS -> empty acknowledgement -> MSP_UPDATE_STATUS
MSP_UPDATE_GET_DIAGNOSTICS -> MSP_UPDATE_DIAGNOSTICS
```

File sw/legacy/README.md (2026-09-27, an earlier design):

# Legacy notebooks

This directory contains older specialized WULPUS PRO notebooks retained for
reference and reproducibility:

- `wulpus_pro_gui.ipynb`
- `wulpus_pro_gui_tgc.ipynb`
- `wulpus_pro_cmuts_gui.ipynb`
- `wulpus_pro_env.ipynb`

For current USB CDC, Wi-Fi, or BLE operation, use
[`../wulpus_pro_example.ipynb`](../wulpus_pro_example.ipynb). The legacy
notebooks may depend on older APIs and are not maintained as the primary usage
path.

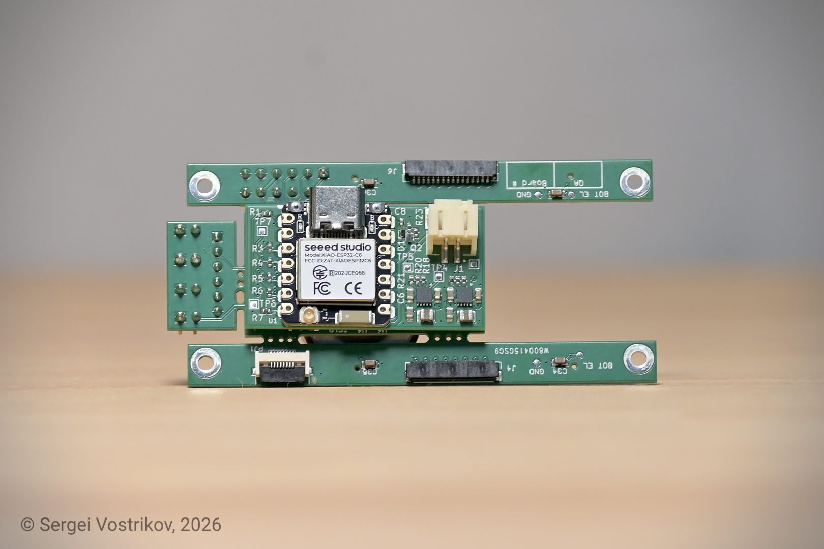
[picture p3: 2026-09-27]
docs/images/v1_2/full_system_top.jpg

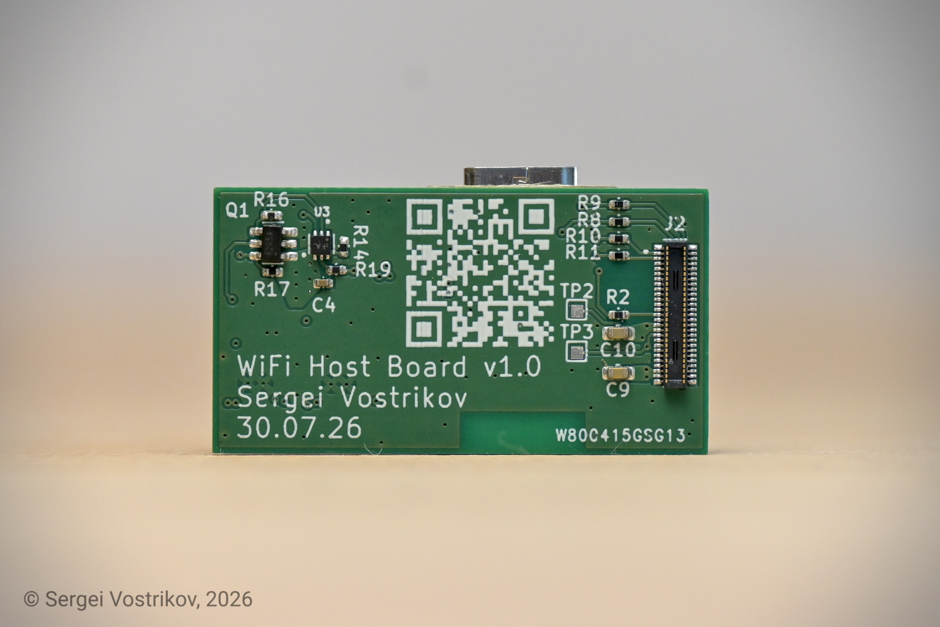
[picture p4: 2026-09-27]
docs/images/v1_2/wifi_board_bottom.jpg

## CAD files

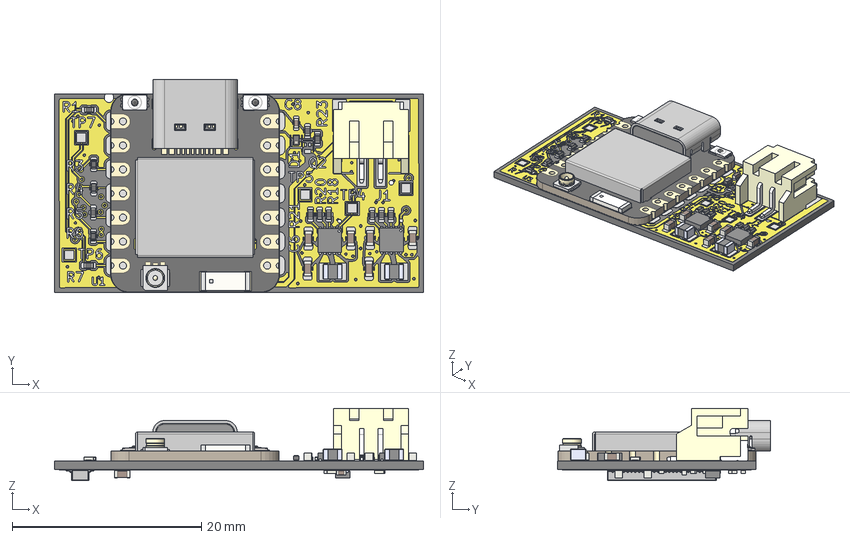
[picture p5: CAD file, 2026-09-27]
hw/wulpus_wifi_host_pcb/docs/wulpus_pro_wifi_host.step
39.0 x 22.5 x 7.65 mm
R_0402_1005Metric x 23
DFE201612R-H-1R0M=P2 x 2
C_0603_1608Metric x 8
D_SOD-882
C_0402_1005Metric x 2
TPS7A9201DSKT x 2
BOSS-EXTRUDE14_8_
BOSS-EXTRUDE7_4_
BOSS-EXTRUDE7_3_
BOSS-EXTRUDE14_4_
BOSS-EXTRUDE14_2_
BOSS-EXTRUDE14_11_
BOSS-EXTRUDE7_7_
BOSS-EXTRUDE14_9_
BOSS-EXTRUDE14_3_
BOSS-EXTRUDE14_7_
MIRROR2
BOSS-EXTRUDE14_5_
BOSS-EXTRUDE14_12_
BOSS-EXTRUDE7_8_
BOSS-EXTRUDE7_1_
BOSS-EXTRUDE14_10_
BOSS-EXTRUDE7_9_
BOSS-EXTRUDE14_6_
BOSS-EXTRUDE14_1_
BOSS-EXTRUDE7_6_
BOSS-EXTRUDE7_2_
CUT-EXTRUDE5
BOSS-EXTRUDE7_5_
U.FL Connector v1
Shield
SKTAAAE010 v1 x 2
KH5220-A36 (Ceramic Antenna) v2
S2B-PH-SM4-TB(LF)(SN)
DSE6
DF40C-40DP-0.4V.1
wulpus_pro_wifi_host_copper
wulpus_pro_wifi_host_pad
wulpus_pro_wifi_host_via
wulpus_pro_wifi_host_silkscreen x 2
wulpus_pro_wifi_host_PCB

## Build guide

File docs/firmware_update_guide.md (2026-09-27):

# Firmware update guide

This guide explains how to install released ESP32-C6 and MSP430FR5043 firmware
on a WULPUS Pro Max WiFi host PCB connected to an Acquisition PCB. Use the
packaged files attached to the corresponding project release on GitHub.

> **Note:** This workflow is suitable for freshly fabricated and assembled
> boards with blank controllers. It installs the complete ESP32 image first,
> then uses the running ESP32 and the WiFi host PCB's integrated JTAG
> connections to program the MSP430. No external programmer is required for
> normal initial provisioning.

## Requirements

- A WiFi host PCB connected to the Acquisition PCB.
- A data-capable USB-C cable and stable power throughout the update.
- The [Python software environment](../sw/README.md#how-to-get-started),
  including the `flash` dependency group.
- `wulpus-pro-max-esp32-<version>.zip` for an ESP32 update.
- `wulpus-pro-max-msp430-<version>.zip` for an MSP430 update.

Close the acquisition GUI, serial monitors, and any other program using the
ESP32 COM port. Disconnect an external MSP-FET before updating the MSP430.

> The integrated MSP430 updater requires the JTAG connections on the WiFi host
> PCB. It is not available with a standalone XIAO ESP32-C6 connected through
> the Acquisition PCB's Dupont headers.

## Open the updater

From the `sw` directory, start Jupyter and open
`wulpus_pro_firmware_update.ipynb`:

```powershell
uv sync --group flash
uv run jupyter notebook
```

## Update the ESP32

On a freshly fabricated board, perform this step before attempting the MSP430
update.

1. In the ESP32 section, refresh the port list and select the ESP32-C6 port.
2. Select the released ESP32 ZIP. The GUI verifies its product, target, flash
   layout, version, and image checksums.
3. Confirm that USB and power will remain connected, then click **Flash ESP32**.
4. Wait for writing, verification, reset, and USB re-enumeration to finish.

The normal update preserves the device configuration and saved Wi-Fi
credentials. If automatic bootloader entry fails, hold **BOOT**, press and
release **RESET**, release **BOOT**, and retry.

## Update the MSP430

Update the ESP32 first when both controllers need new firmware.

1. Wait for the ESP32 to restart, then refresh and open its COM port in the
   MSP430 section.
2. Select the released MSP430 ZIP. The GUI verifies its firmware SHA-256 and
   container format before upload. Click **Upload and program**.
3. Keep USB and system power connected while the image is uploaded and the
   ESP32 restarts to program and verify the MSP430.
4. Reconnect and click **Check status** if the result is not restored
   automatically. Require `COMPLETE` with error zero.

`COMPLETE` confirms programming and verification. Reopen the acquisition
notebook, apply a configuration, and verify normal acquisition to confirm that
the full system operates correctly.

## Verify the installed versions

Open `wulpus_pro_example.ipynb`, connect to the device, and confirm the reported
ESP32 and MSP430 versions match the selected release packages. The MSP430
version becomes available after the first successful acquisition-configuration
exchange.

## Recovery

An interrupted MSP430 update is not resumed automatically, and the MSP430 has
no dual-image rollback. Reconnect and retry the complete update. If the ESP32
cannot identify or program the MSP430, recovery may require an external
programmer.

Developers investigating the updater implementation should use the
[ESP32 MSP430 updater implementation guide](../fw/esp32/docs/msp430_update_guide.md).

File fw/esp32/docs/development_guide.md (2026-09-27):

# ESP32 firmware development guide

Install the toolchain and build from source when developing firmware or
preparing a board that does not already have firmware installed.

## Contents

- [Code formatting](#code-formatting)
- [Requirements](#requirements)
- [Supported boards](#supported-boards)
- [Install ESP-IDF](#install-esp-idf)
- [Configure, compile, and flash](#configure-compile-and-flash)
  - [Configure](#configure)
  - [Compile the firmware](#compile-the-firmware)
  - [Flash the firmware](#flash-the-firmware)
  - [Create a merged firmware image](#create-a-merged-firmware-image)
  - [Pin mapping](#pin-mapping)

## Requirements

- ESP-IDF 6.0.1
- A [supported host board](#supported-boards), listed below
- A data-capable USB-C cable
- The ESP-IDF command-line environment or official ESP-IDF VS Code extension

## Supported boards

- **[WULPUS Pro Max WiFi host PCB](../../../hw/wulpus_wifi_host_pcb)** — the primary
  and recommended XIAO ESP32-C6-based host board, compatible with the WULPUS Pro Max
  connector. It is highly integrated: it supplies power to the Acquisition PCB,
  provides Wi-Fi and USB connectivity, and supports MSP430 firmware flashing.
- **[Seeed Studio XIAO ESP32-C6](https://www.seeedstudio.com/Seeed-Studio-XIAO-ESP32C6-p-5884.html)** —
  a standalone development alternative for firmware development and bench
  testing. Connect its pins to the WULPUS PRO Acquisition PCB according to the
  [pin mapping](#pin-mapping) below. This setup does not supply the Acquisition
  PCB power rails; all required power domains must be provided by external lab
  power supplies.

Both boards use the same XIAO defaults, build commands, GPIO assignments, and
WULPUS PRO connector mapping documented below.

Run all `idf.py` commands below from `fw/esp32`. From the repository root:

```powershell
Set-Location fw/esp32
```

The commands shown use PowerShell continuation/quoting syntax. Existing
`sdkconfig.xiao` files retain saved values; compare them with the XIAO defaults
when updating.

## Install ESP-IDF

Install **ESP-IDF 6.0.1** and its ESP32-C6 toolchain before configuring the
firmware. Espressif's Installation Manager is the recommended method:

```text
eim install -i v6.0.1
```

Open an activated ESP-IDF terminal and verify:

```text
idf.py --version
```

See [ESP-IDF toolchain setup](esp_idf_toolchain_guide.md) for Windows, Linux, macOS,
VS Code, manual installation, and troubleshooting instructions.

## Configure, compile, and flash

### Configure

Configure the project with the XIAO board defaults:

```powershell
idf.py -B build-xiao `
  -D SDKCONFIG=sdkconfig.xiao `
  -D SDKCONFIG_DEFAULTS="sdkconfig.defaults;sdkconfig.defaults.esp32c6;boards/xiao-esp32c6.defaults" `
  reconfigure
```

Alternatively, use the official ESP-IDF VS Code extension. Set its build
directory to `build-xiao` and its SDKConfig file to `sdkconfig.xiao`, select the
board's serial port, then use the **Build** and **Flash** buttons in the VS Code
status bar instead of the commands below. See Espressif's official
[Build Your Project tutorial](https://docs.espressif.com/projects/vscode-esp-idf-extension/en/latest/buildproject.html),
which continues to the flashing instructions.

### Compile the firmware

The ESP32 application version is read from
[`firmware_version.txt`](../firmware_version.txt). Update that file with a
`major.minor.patch` release before compiling; CMake rejects other formats. The
version must match the corresponding release heading in
[`CHANGELOG.md`](../CHANGELOG.md), for example `firmware_version.txt` value
`1.1.0` matches the `## [1.1.0]` changelog entry.

```powershell
idf.py -B build-xiao build
```

The compiled application and supporting bootloader and partition-table images
are written to `build-xiao`.

### Flash the firmware

Connect the selected board to the PC with a data-capable USB-C cable. Replace
`COM10` with the port assigned by Windows:

```powershell
idf.py -B build-xiao -p COM10 flash
```

Use the full `flash` command above when upgrading older firmware so the
bootloader, partition table, and application are installed together.

### Create a merged firmware image

For a single image to distribute to a fresh ESP32, run
`idf.py -B build-xiao merge-bin` after building. Flash the resulting
`build-xiao/merged-binary.bin` at `0x0`. The application
`wulpus-pro-fw.bin` alone does not include the bootloader or partition table.

### Pin mapping

| Signal | ESP32-C6 GPIO | XIAO pin | WULPUS PRO Acquisition PCB connection |
|---|---:|---|---|
| `SPI_SS` | 17 | D7 | X3.4 |
| `SPI_CLK` | 18 | D10 | X3.3 |
| `SPI_MISO` | 20 | D9 / MISO | X3.1 |
| `SPI_MOSI` | 19 | D8 / SCK | X3.2 |
| `DATA_READY` | 1 | D1 | X4.2 |
| `MSP_RST_N` | 0 | D0 | X1.5 |

For a standalone XIAO, connect a common ground and verify the Acquisition PCB
schematic and connector pinout before powering the boards.

## Code formatting

Project-owned ESP32 C sources use clang-format, pinned in the development
dependencies of `sw/pyproject.toml` and `sw/uv.lock`. The commands below reuse
`sw/.venv`; do not create another Python environment or install a formatter
into the ESP-IDF environment. Install `uv` as described in the
[software setup](../../../sw/README.md#how-to-get-started) if needed.

From the repository root, apply formatting before submitting changes:

```powershell
uv run --locked --project sw python scripts/format_esp32_fw.py --fix
```

Check without modifying files:

```powershell
uv run --locked --project sw python scripts/format_esp32_fw.py --check
```

GitHub Actions runs the same script with `--only-group dev` on `uv run`,
installing only development tools in its temporary runner environment. Locally,
use the commands above to retain the complete software environment.

`uv run` installs locked dependencies into the existing software environment
when needed. The script invokes that environment's clang-format binary, so an
ESP-IDF formatter on PATH does not change the result. Rules are in
[`fw/esp32/.clang-format`](../.clang-format).

Scope is tracked `.c` and `.h` files under `fw/esp32/main/` and
`fw/esp32/components/`, excluding bundled TI code in
`components/msp430_programmer/ti/`. Build output, managed components, MSP430,
and nRF52 firmware are outside this scope. Stage new source files with
`git add` before running the script. If adding third-party sources under the
selected directories, update `EXCLUDED` in the script first.

A failing CI check means formatting needs attention: run `--fix`, review the
diff, and commit the formatted files. Keep broad formatting changes separate
from functional changes. Build the firmware after the initial formatting pass.
Optional editor format-on-save should use the same pinned formatter and config.

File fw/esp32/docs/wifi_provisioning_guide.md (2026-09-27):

# Wi-Fi provisioning guide

The firmware uses ESP-IDF network provisioning over a temporary SoftAP. Wi-Fi
credentials are stored in non-volatile storage and reused after reset or power
cycling.

## Contents

- [When provisioning starts](#when-provisioning-starts)
- [Provisioning parameters](#provisioning-parameters)
- [Boot sequence](#boot-sequence)
- [Reprovisioning](#reprovisioning)
- [USB operation during provisioning](#usb-operation-during-provisioning)
- [Troubleshooting](#troubleshooting)

Provisioning controls only Wi-Fi setup. It does not own the WULPUS Pro Max PC
protocol session, and native USB CDC remains available while the board is
waiting for credentials or network association.

## When provisioning starts

At boot, the persistent Wi-Fi manager loads `wulpus_pro/device_cfg` and checks
ESP-IDF's separate credential storage:

- If Wi-Fi is disabled at boot, the radio remains stopped and USB stays available.
- If no credentials exist and `auto_provision` is enabled, the board starts the SoftAP provisioning service.
- If no credentials exist and `auto_provision` is disabled, the board remains USB-only.
- If credentials exist, the provisioning manager is deinitialized and the
  board immediately attempts to join the stored network.
- If association is lost later, the station reconnects automatically.

The TCP listener starts only after the station obtains an IP address. The USB
listener starts independently during normal firmware startup.

## Provisioning parameters

| Setting | Current value |
|---|---|
| Scheme | SoftAP |
| SoftAP name | `PROV_WULPUS_PRO_XXXXXX` |
| Name suffix | Last three bytes of the station MAC address, uppercase hexadecimal |
| Provisioning security | ESP-IDF Security 1 |
| Proof of possession | `CONFIG_PROVISIONER_POP`; default `abcd1234` |
| SoftAP service key | None |

Use an ESP-IDF-compatible provisioning client, select the
`PROV_WULPUS_PRO_XXXXXX` device, enter the proof-of-possession value, and provide
the target Wi-Fi SSID and password. The provisioning service validates the
credentials by connecting to the requested access point.

The proof-of-possession default is suitable for development only. Set a unique
value through `CONFIG_PROVISIONER_POP` for deployed devices.

## Boot sequence

```mermaid
flowchart TD
    BOOT["Boot"] --> ENABLED{"Wi-Fi enabled at boot?"}
    ENABLED -->|No| USB["Wi-Fi disabled; USB CDC remains available"]
    ENABLED -->|Yes| CHECK{"Stored Wi-Fi credentials?"}
    CHECK -->|No| AUTO{"Automatic provisioning enabled?"}
    AUTO -->|No| USB
    AUTO -->|Yes| AP["Start PROV_WULPUS_PRO_XXXXXX SoftAP"]
    AP --> CREDS["Receive SSID and password"]
    CREDS --> TEST{"Association succeeds?"}
    TEST -->|No| AP
    TEST -->|Yes| STORE["Keep credentials in NVS"]
    CHECK -->|Yes| STA["Start Wi-Fi station"]
    STORE --> STA
    STA --> IP["Obtain IP address"]
    IP --> MDNS["Advertise wulpus_pro TCP service via mDNS"]
    IP --> TCP["Start TCP listener on port 2121"]
```

The persistent device configuration selects no, minimum-modem, or maximum-modem
Wi-Fi power saving. It also selects TWT; the firmware build must include
`CONFIG_PROVISIONER_TWT_ENABLED` for TWT to be available. TWT is suspended while
a WULPUS Pro Max protocol session is active.

`auto_provision` is a persistent policy and is not cleared after successful
provisioning. It is consulted only when Wi-Fi is enabled at boot and no saved
credentials exist. Saved credentials always take priority.

## Reprovisioning

When `CONFIG_WP_DOUBLE_RESET` is enabled, resetting the ESP32 twice within
`CONFIG_WP_DOUBLE_RESET_TIMEOUT` requests a provisioning reset. The default
timeout declared by the project is 2000 ms. On the second boot, stored Wi-Fi
provisioning state is cleared and the SoftAP workflow starts again.

Check the generated `sdkconfig` for the firmware being flashed. If it contains:

```text
# CONFIG_WP_DOUBLE_RESET is not set
```

the double-reset trigger is unavailable in that build.

Wi-Fi credentials can also be set or cleared over USB CDC using the PC protocol
commands. See the [host software documentation](../../../sw/README.md) for the
configuration interface. These operations update persistent storage, and
`RESET` applies the change. SSIDs and passwords cannot be read through the
protocol and are never written to firmware logs.

## USB operation during provisioning

USB CDC can be used even when:

- the device has never been provisioned;
- the configured access point is unavailable;
- the station is reconnecting; or
- the provisioning client is active.

A physical USB connection does not prevent later TCP use. Close the active USB
protocol session before connecting over TCP; see
[Firmware architecture](firmware_architecture.md#usb-and-wi-fi-session-switching).

## Troubleshooting

- **No device appears in Wi-Fi discovery:** confirm provisioning completed and
  the PC and ESP32 are on a network that permits mDNS and peer-to-peer TCP.
- **SoftAP does not appear:** credentials may already be stored. Check whether
  the build enables the double-reset trigger.
- **Provisioning repeatedly rejects credentials:** verify the SSID/password and
  ensure the access point is reachable by an ESP32-C6. With
  `CONFIG_PROVISIONER_RESET_ON_FAILURE`, the provisioning state machine resets
  after the configured number of failed attempts.
- **TCP reports `BUSY`:** another transport owns the WULPUS Pro Max protocol
  session. Close the USB session before retrying TCP.

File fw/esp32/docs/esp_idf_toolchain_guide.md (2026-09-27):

# ESP-IDF toolchain setup guide

This firmware is developed and tested with **ESP-IDF 6.0.1** targeting
ESP32-C6. Use the same version when reproducing builds unless a later version
has been explicitly validated by the project.

## Contents

- [Recommended installation with EIM](#recommended-installation-with-eim)
- [VS Code setup](#vs-code-setup)
- [Manual Git installation](#manual-git-installation)
- [Verify the installation](#verify-the-installation)
- [Configure this project](#configure-this-project)
- [Flashing and USB ownership](#flashing-and-usb-ownership)
- [Common problems](#common-problems)

ESP-IDF is more than a compiler. A complete installation includes:

- the ESP-IDF framework and build scripts;
- the RISC-V compiler and debugger for ESP32-C6;
- CMake and Ninja;
- Python and an ESP-IDF-managed Python environment;
- flashing tools such as esptool; and
- optional OpenOCD tools for JTAG debugging.

The recommended installer for ESP-IDF 6.0 and newer is Espressif's ESP-IDF
Installation Manager (EIM). See the official ESP32-C6
[ESP-IDF 6.0.1 Get Started guide](https://docs.espressif.com/projects/esp-idf/en/v6.0.1/esp32c6/get-started/index.html).

## Recommended installation with EIM

Install **ESP-IDF v6.0.1**, not merely whichever release is currently marked
latest. In the EIM graphical interface, use a custom/expert installation when
necessary to select version 6.0.1 and ESP32-C6 support.

The EIM command-line equivalent is:

```text
eim install -i v6.0.1
```

If the command is unavailable or version selection needs interaction, run:

```text
eim wizard
```

### Windows

Install the EIM GUI with Windows Package Manager:

```powershell
winget install Espressif.EIM
```

Alternatively, install the CLI-only package:

```powershell
winget install Espressif.EIM-CLI
```

Open EIM and install ESP-IDF 6.0.1 with ESP32-C6 tools. EIM checks for Git and
Python and offers to install missing prerequisites. ESP-IDF 6.0.1 requires
Python 3.10 or newer.

After installation, use the ESP-IDF terminal/environment created by EIM rather
than an ordinary PowerShell window. The activated terminal supplies `IDF_PATH`,
the ESP-IDF Python environment, CMake, Ninja, the RISC-V toolchain, and
`idf.py`.

Official instructions:
[Installation on Windows](https://docs.espressif.com/projects/esp-idf/en/v6.0.1/esp32c6/get-started/windows-setup.html).

### Linux

On Debian/Ubuntu, EIM can be installed from Espressif's APT repository:

```bash
echo "deb [trusted=yes] https://dl.espressif.com/dl/eim/apt/ stable main" \
  | sudo tee /etc/apt/sources.list.d/espressif.list
sudo apt update
sudo apt install eim
```

Use `eim-cli` instead of `eim` for a CLI-only installation. RPM-based systems
can use Espressif's DNF repository described in the official guide.

Then install ESP-IDF 6.0.1:

```bash
eim install -i v6.0.1
```

Official instructions:
[Installation on Linux](https://docs.espressif.com/projects/esp-idf/en/v6.0.1/esp32c6/get-started/linux-setup.html).

### macOS

Install the prerequisites and EIM with Homebrew:

```bash
brew install libgcrypt glib pixman sdl2 libslirp dfu-util cmake python
brew tap espressif/eim
brew install --cask eim-gui
```

For a CLI-only EIM installation, use:

```bash
brew install eim
eim install -i v6.0.1
```

Official instructions:
[Installation on macOS](https://docs.espressif.com/projects/esp-idf/en/v6.0.1/esp32c6/get-started/macos-setup.html).

## VS Code setup

1. Install Visual Studio Code.
2. Install the official **Espressif IDF** extension.
3. Open the Command Palette.
4. Run **ESP-IDF: Open ESP-IDF Installation Manager** if ESP-IDF is not yet
   installed.
5. Run **ESP-IDF: Select Current ESP-IDF Version** and select the 6.0.1 setup.
6. Open this `fw/esp32` directory as the project folder.
7. Run **ESP-IDF: Doctor Command** if the extension does not find the toolchain
   or connected board.

The extension stores the selected ESP-IDF setup for the workspace and configures
the required environment variables. Do not mix a workspace-selected EIM setup
with stale manually configured `IDF_PATH`, `IDF_TOOLS_PATH`, or
`IDF_PYTHON_ENV_PATH` values.

Official instructions:
[Install ESP-IDF and tools in VS Code](https://docs.espressif.com/projects/vscode-esp-idf-extension/en/latest/installation.html).

## Manual Git installation

Use this path for CI or when EIM cannot be used. On Linux/macOS:

```bash
mkdir -p ~/esp
cd ~/esp
git clone --recursive --branch v6.0.1 \
  https://github.com/espressif/esp-idf.git
cd esp-idf
./install.sh esp32c6
. ./export.sh
```

The environment activation applies only to the current shell. Run:

```bash
. ~/esp/esp-idf/export.sh
```

in each new terminal before invoking `idf.py`. The ESP-IDF repository must be
cloned recursively because the framework uses Git submodules.

For Windows, EIM is strongly preferred because it installs and coordinates the
required compiler, Python environment, build tools, and shell shortcuts.

## Verify the installation

Open an activated ESP-IDF shell and run:

```text
idf.py --version
python --version
cmake --version
ninja --version
riscv32-esp-elf-gcc --version
```

The first command should report ESP-IDF v6.0.1. Python must be at least 3.10.
The remaining commands must resolve without manually adding individual tool
directories to `PATH`.

On Windows, also confirm that the board appears in Device Manager when connected
with a data-capable USB cable. Note the assigned COM port for flashing.

## Configure this project

From an activated ESP-IDF shell, change to this directory:

```text
cd path/to/wulpus-pro/fw/esp32
```

Then follow the board-specific commands in the
[development guide](development_guide.md). The WULPUS Pro Max WiFi host PCB is
the primary host board and uses the XIAO ESP32-C6 configuration.

The first configure/build may download managed ESP-IDF components declared by
the project. Internet access is therefore normally required even after the base
toolchain is installed, unless the component cache has already been populated.

## Flashing and USB ownership

Build and flash with the board-specific build directory described in the
[development guide](development_guide.md). For example:

```powershell
idf.py -B build-xiao build
idf.py -B build-xiao -p COM10 flash
```

For distribution as one complete ESP32 image, run
`idf.py -B build-xiao merge-bin` and flash `build-xiao/merged-binary.bin` at
`0x0`. An application-only `.bin` is insufficient for a fresh board. The current
partition table also adds the required 256 KiB MSP430 image staging partition;
flash the updated table when upgrading an older installation.

MSP430 firmware is built separately with CCS and uploaded through the
[firmware update workflow](../../../docs/firmware_update_guide.md). Its TI-TXT
file is not an ESP32 image and must not be passed to the ESP32 flasher.

Replace `COM10` with the actual ESP32-C6 port. Close the Python GUI, Tera Term,
ESP-IDF monitor, and any other serial application before flashing; only one
process can own the CDC COM port on Windows.

Do not leave `idf.py monitor` running during normal WULPUS USB acquisition. The
production configuration reserves native USB CDC for binary PC protocol data
and disables the application console.

## Common problems

- **`idf.py` is not recognized:** the terminal is not running the activated
  ESP-IDF environment. Reopen the EIM/ESP-IDF shell or source `export.sh`.
- **Wrong ESP-IDF version:** select/install v6.0.1 and verify with
  `idf.py --version` before reconfiguring.
- **CMake or compiler not found:** do not install random versions into the
  project environment; repair/select the EIM setup so its managed tools are
  used together.
- **COM port cannot be opened:** close the GUI, terminal, monitor, or another
  flashing process that owns it.
- **JTAG flash says OpenOCD is not running:** start an ESP-IDF JTAG debug/flash
  configuration, or use serial flashing with `idf.py -p COMx flash`.

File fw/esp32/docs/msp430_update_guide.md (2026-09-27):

# MSP430 updater implementation

The ESP32 stages an MSP430FR5043 firmware image received over USB CDC or TCP,
then programs the MSP430 through four-wire JTAG during the next boot. Users
should follow the central
[firmware update guide](../../../docs/firmware_update_guide.md); this document
describes the ESP32 implementation.

## Contents

- [JTAG implementation](#jtag-implementation)
- [Staging and boot lifecycle](#staging-and-boot-lifecycle)
- [Failure and recovery behavior](#failure-and-recovery-behavior)
- [Image container](#image-container)

## JTAG implementation

The JTAG programmer is based on TI's
[MSP430 Programming With the JTAG Interface (SLAU320AJ)](https://www.ti.com/lit/pdf/slau320)
and its MSP430 FRAM Replicator reference implementation:
[JTAGfunc430FR.c](../components/msp430_programmer/ti/JTAGfunc430FR.c) and
[JTAGfunc430FR.h](../components/msp430_programmer/ti/JTAGfunc430FR.h).
[msp430_jtag.c](../components/msp430_programmer/msp430_jtag.c) and the adapted
[LowLevelFunc430Xv2.h](../components/msp430_programmer/ti/LowLevelFunc430Xv2.h)
provide the ESP32 GPIO interface.

The WiFi host PCB routes the ESP32-C6 JTAG GPIOs to the MSP430. A standalone
XIAO connected through the Acquisition PCB's Dupont headers cannot use the
programmer because those JTAG signals are not exposed there. An attached
MSP-FET must not drive the signals concurrently.

## Staging and boot lifecycle

The ESP32 receives the versioned section image through the update protocol and
stores it in the 256 KiB `msp_image` data partition defined by
`partitions.csv`. Each transfer is CRC checked before being accepted. Commit
persists the pending-update state and restarts the ESP32.

Early in the following boot, the programmer validates the container, enters
MSP430 JTAG, erases and writes the declared FRAM sections, reads them back for
verification, resets the target, and persists the final state and diagnostics.
Normal USB and Wi-Fi services start after this boot-time operation.

See the [MSP430 firmware update protocol](msp430_update_protocol.md) for command,
status, and diagnostic layouts.

## Failure and recovery behavior

The ESP32 temporarily disconnects from USB while it programs and verifies the
MSP430 during startup. `COMPLETE` confirms programming and readback
verification; it does not prove subsequent application behavior.

An interrupted update is not resumed automatically, and the MSP430 has no
dual-image rollback. A new complete image must be uploaded after the ESP32
returns. Identification or JTAG failures may require recovery with an external
programmer. Persisted status and diagnostics record the last stage and detected
JTAG and device identifiers.

## Image container

All integers are little-endian. TI-TXT or Intel HEX input is converted to an
`MSP1` container before upload; `.out` ELF and raw flat `.bin` files are not
accepted directly.

| Header field | Bytes | Value |
|---|---:|---|
| magic | 4 | `0x3150534D` (`MSP1`) |
| version, header_size | 2 each | `1`, `24` |
| target_id | 4 | `0x00005043` |
| total_size | 4 | Header + section table + data |
| image_crc32 | 4 | CRC of concatenated section data |
| section_count, flags | 2 each | 1-64 sections; flags zero |

The header is followed by one 12-byte `(address, length, data_crc32)` descriptor
per section, then the section data in table order. CRCs use the reflected
CRC-32 polynomial `0xEDB88320`.

Sections must be nonoverlapping and word-aligned, lie in
`[0x6000, 0x15FF8)`, and exclude `[0xFF80, 0xFF90)` (JTAG/BSL signatures).
Interrupt vectors outside that protected range are allowed. The text importer
removes erased `0xFF` signature placeholders, rejects other signature contents,
rejects odd start addresses, and pads odd data lengths with `0xFF`.

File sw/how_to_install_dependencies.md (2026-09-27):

# How to install Python requirements

The software project uses `uv` for Python dependency management.

1. Install `uv`: https://docs.astral.sh/uv/getting-started/installation/
2. Open a terminal in the `sw` folder.
3. Create the local environment and install dependencies:

```bash
uv sync
```

4. Start Jupyter from the same folder:

```bash
uv run jupyter notebook
```

5. Open `wulpus_pro_example.ipynb` in the browser and follow its instructions. Older notebook variants are archived under `legacy/`.

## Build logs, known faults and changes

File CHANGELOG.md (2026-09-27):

# Changelog

All main changes to this project will be documented in this file.
For the detailed description, please explore nested folders and corresponding CHANGELOG.md files (e.g. for PCB projects or firmware). 

The format is based on [Keep a Changelog](https://keepachangelog.com/en/1.0.0/),
and this project adheres to [Semantic Versioning](https://semver.org/spec/v2.0.0.html).

## [Unreleased]

## [2.0.0] - 2026-09-27

### Removed

- Dropped ESP32-C6-DEVKITM-1 evaluation kit support, including its board defaults
  and development setup instructions.

### Added

- Added release tooling for validated ESP32 ZIPs, versioned MSP430 `.mspfw`
  images, and minimal PCB fabrication packages, including checksums, a unified
  graphical firmware updater, and development-script documentation.
- Added ESP32 and MSP430 running-firmware version reporting through the common
  USB/TCP protocol and main acquisition GUI.
- Added pinned clang-format tooling in the existing software development
  environment, an ESP32 formatting script, CI checks, and developer instructions.
- Added a host-board comparison covering the integrated WiFi host PCB,
  standalone XIAO ESP32-C6, and legacy nRF52 BLE solution.
- Added MSP430FR5043 firmware updating through the ESP32 over USB CDC or Wi-Fi,
  with staged images, boot-time JTAG programming/verification, and saved status
  and diagnostics.
- Documented updater wiring, partition requirements, protocol, and recovery,
  plus TI-TXT export. CCS Debug now exports TI-TXT.
- Added versioned ESP32 device configuration in NVS with reboot-only Wi-Fi
  boot, automatic provisioning, modem power-save, and TWT policies.
- Added protocol and Python APIs for complete device-configuration replacement,
  Wi-Fi status, and write-only credential replacement or clearing.
- Added a USB CDC device-configuration GUI to the main WULPUS PRO example
  notebook.
- Added an interactive viewer for GUI- and profiler-generated NPZ acquisitions,
  including TX/RX configuration filtering, acquisition navigation, band-pass
  filtering, Hilbert-envelope extraction, and controllable acquisition replay
  with stable Y-axis limits.
- Added exact GUI-saved acquisition configuration loading to the USB profiler,
  including persisted TX/RX mask arrays for reproducible headless tests and
  optional GUI-compatible NPZ acquisition output.
- Added ESP-IDF 6.0.1 installation and validation documentation for the ESP32
  firmware toolchain across Windows, Linux, macOS, and VS Code.
- Added structured ESP32 documentation covering runtime architecture,
  provisioning, the MSP430 SPI/configuration protocol, and the common USB/TCP
  PC protocol.
- Added native ESP32-C6 USB CDC communication as a wired alternative to Wi-Fi,
  using the existing WULPUS command and acquisition-data protocol.
- Added concurrent TCP/USB session arbitration and an explicit `BUSY` protocol
  response when another transport owns the device.
- Added a standalone Python USB frame-rate profiler.
- Added runtime acquisition diagnostics and host commands for reading and
  clearing sticky ESP32 errors.
- Added GUI stall diagnostics showing ESP32 acquisition errors and relevant
  buffer, SPI, transmission, and discard counters.

### Fixed

- Bound GUI acquisition to the transport that was actually opened and contained
  background transport failures in GUI status reporting.
- Embedded the NPZ viewer's live ipympl canvas directly so replay and slider
  updates use one visible plot instead of creating duplicate figure windows.
- Prevented high-frame-rate GUI processing from stalling USB acquisitions by
  keeping filtering, plotting, widget updates, and per-frame logging out of the
  continuous receive path.
- Prevented optional profiler data saving from adding per-frame NumPy copies to
  the high-rate USB receive loop.
- Fixed GUI acquisitions stalling partway through a run when the device's
  continuous acquisition sequence number exceeded the requested frame count.
- Kept the ESP32-C6 out of automatic light sleep whenever a USB host is
  connected, preventing missed USB CDC commands and enumeration failures.
- Fixed Windows ESP32-C6 CDC opening, partial writes, receive latency, and
  asynchronous acquisition frames arriving while command acknowledgements are
  pending.

### Changed

- Updated the README and full specifications with measured receive performance,
  streaming, power, mechanics, and arXiv sourcing.
- Renamed the user-facing project branding and repository from WULPUS PRO to
  WULPUS Pro Max.
- Released the WULPUS Pro Max WiFi host PCB v1.0.1 with updated title blocks,
  silkscreen, and regenerated design and fabrication outputs.
- Clarified in the README and host-board guide that the legacy nRF52 BLE option
  may suit lower-power applications, but is unsupported, is not recommended for
  new setups, and requires additional integration work.
- Polished the WiFi host PCB description and aligned the README and host
  documentation with support for up to 500 Hz PRF over Wi-Fi/TCP or USB CDC,
  external Adafruit battery power through a standard JST connector, USB battery
  charging, and integrated battery protection.
- Added the `docs/images/v1_2` hardware photos, updated the README gallery,
  captions and alt text, and extended image authorship coverage.
- Updated the project description and clarified attribution.
- Renamed `SET_CONFIG` to `SET_ACQ_CONFIG` while retaining wire ID `0x57`.
- Consolidated the supported USB CDC, Wi-Fi, and BLE workflow in
  `sw/wulpus_pro_example.ipynb` and moved older notebooks to `sw/legacy`.
- Reworked Wi-Fi provisioning as a persistent manager and made the persistent
  TCP thread wait for Wi-Fi connectivity.
- Added receive-only and all-channel USB profiler presets with explicit DC-DC
  timing, and corrected the MSP430 documentation to place DC-DC turn-on before
  the acquisition-period event.
- Documented the WULPUS PRO WiFi host PCB and its integrated XIAO ESP32-C6 as
  the primary ESP32 host, replacing the obsolete recommendation to use an
  external XIAO while the host PCB was under test.
- Increased the ESP32 DMA acquisition frame pool from 8 to 64 slots to tolerate
  longer host USB/GUI scheduling pauses at high frame rates.
- Refactored the ESP32 firmware into focused board, control, protocol, link,
  frame-storage, and task components around a transport-independent session
  layer. SPI acquisition and packet transmission now have independent owners
  connected by a zero-copy frame pool, and the acquisition owner is split into
  command/state, scheduler, DATA_READY/SPI-handshake, and frame-ownership
  modules.
- Reserved the native USB CDC interface for binary protocol traffic and disabled
  the conflicting application console in the default ESP32-C6 configuration.
- Made USB communication available before Wi-Fi provisioning or association
  completes.

## [1.1.0] - 2026-08-22

### Added

- Added the WULPUS PRO Wifi host PCB design (KiCad) and fabrication outputs.
- Added board-specific hardware licensing documentation and a separate `hw/LICENSE_ETH` file for the ETH Zurich PCB designs.
- Expanded the hardware README with the represented PCB designs, their CAD formats, purposes, and license assignments.
- Documented the WULPUS PRO Wifi host PCB testing status, planned battery and USB operating modes, and temporary use of an external XIAO ESP32-C6.
- Documented that `kicad_us_lib` is a private, development-only submodule and advised external users to generate project-specific KiCad libraries from the project files.
- Added the `kicad_us_lib` repository as a Git submodule under `hw/kicad_us_lib`.
- Added private-submodule cloning guidance for maintainers and external users to the root README.
- Added a linked table of contents to the root README.
- Added the WULPUS PRO arXiv preprint citation and BibTeX entry to the root README.
- Added PCBWay shared-project production and assembly information to the hardware README.
- Expanded the root README acknowledgements.

## [1.0.0] - 2026-07-11

### Added

- Added ESP32-C6 Wi-Fi firmware support for the Seeed Studio XIAO ESP32-C6 board, including board-specific defaults and README pin mapping.
- Added MSP430 board reset control logic to the ESP32 Wi-Fi firmware.
- Added a Python Wi-Fi example notebook for discovery, connection setup, configuration transfer, and data acquisition over the ESP32 TCP link.
- Added Apache-2.0 license headers to ESP32 firmware source files and Python support scripts.
- Added a documentation changelog under `docs/`.
- Added image documentation README with CC BY-ND 4.0 license information.
- Added WULPUS PRO images to the root README hero and hardware photos sections.
- Added the WULPUS PRO system diagram to the root README.
- Added `uv` project metadata and lockfile for Python dependency management.
- Added a root README specifications section comparing WULPUS PRO with the original WULPUS platform.

### Fixed

- Fixed the MSP430 firmware initialization so the preamplifier power switch is always enabled at startup.
- Fixed the ESP32-C6-DEVKITM-1 board defaults to avoid reusing GPIO2 for both SPI MOSI and MSP430 reset.

### Changed

- Refactored the ESP32 firmware configuration around reusable ESP-IDF defaults, target-specific defaults, and board-specific pinout files.
- Updated the ESP32 project from ESP-IDF 5.4.1 to ESP-IDF 6.0.1.
- Updated ESP32 documentation for tested DevKit and XIAO boards, board selection, flashing, serial port selection, and WULPUS PRO connector pin mappings.
- Updated ESP32 firmware attribution with author information and ESP-IDF example note.
- Reworked the root README introduction with a concise overview of the pulser, acquisition front end, supported transducers, and module form factor.
- Updated project READMEs for repository structure, build instructions, usage flows, firmware links, and WULPUS PRO-specific documentation pointers.
- Migrated Python package management from conda to uv.
- Moved WULPUS PRO full specifications from the root README into `docs/full_specifications.md`.
- Updated gitignore rules.

### Removed

- Removed the old ESP32-C6-DEVKITM-1 MSP430 reset mapping from GPIO2; GPIO2 is used for SPI MOSI and MSP430 reset is now on GPIO3.
- Removed the old Conda `sw/requirements.yml` dependency file.

## [0.1.0] - 2025-05-1

### Added
- Initial release (without official GitHub release)

### Fixed

### Changed

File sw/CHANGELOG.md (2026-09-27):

# Changelog

All notable changes to this project will be documented in this file.

The format is based on [Keep a Changelog](https://keepachangelog.com/en/1.0.0/),
and this project adheres to [Semantic Versioning](https://semver.org/spec/v2.0.0.html).

## [Unreleased]

## [0.2.0] - 2026-09-27

### Added

- Added validated ESP32-C6 release-package flashing through esptool and renamed
  the MSP430 notebook to a unified firmware-update notebook with separate ESP32
  and MSP430 operations.
- Added a firmware-information API and GUI label for the running ESP32 and
  detected MSP430 firmware versions, including reserved Git hash and dirty-state
  fields for future firmware build integration.
- Added USB CDC APIs and a Jupyter GUI for persistent device configuration and
  write-only Wi-Fi credential management.
- Added an interactive Jupyter NPZ viewer with browser upload, direct path
  loading, TX/RX configuration filtering, acquisition navigation, metadata,
  raw ADC plotting, GUI-equivalent band-pass filtering, and Hilbert-envelope
  extraction, plus asynchronous replay from the current slider position at a
  configurable frame rate and a fixed Y-axis range during playback.
- Selectable Wi-Fi and BLE communication transports in `WulpusGuiSingleCh`.
- Native ESP32-C6 USB CDC transport for wired WULPUS Pro Max communication.
- Added a GUI acquisition-status field that reports decoded ESP32 error flags,
  overflow, SPI, transmission, discard, and frame-buffer counters when frame
  reception stalls.
- Added a standalone USB frame-rate profiler with acquisition-number gap,
  timeout, latency, and achieved-FPS reporting.
- Added explicit `simplified` and `active-all` profiler modes; the active mode
  enables every TX/RX channel and fixes DC-DC turn-on at 100 us, while custom
  mode exposes absolute or period-relative DC-DC timing.
- Added profiler loading of GUI-saved acquisition JSON, including complete
  timing/gain settings and TX/RX masks in newly saved configuration files.
- Added optional profiler output in the GUI-compatible NPZ format, with
  period-specific filenames for multi-rate sweeps.
- Added Python APIs for reading versioned ESP32 runtime status and clearing
  selected sticky errors and diagnostic counters.

### Fixed

- Bound acquisition to the communication link that was successfully opened,
  preventing a stale default Wi-Fi link from being used after transport
  selection.
- Caught acquisition-thread transport failures and reported them through the
  GUI instead of emitting uncaught background-thread tracebacks.
- Prevented duplicate NPZ-viewer figure windows by embedding the live ipympl
  canvas directly while preserving interactive slider and replay updates.
- Prevented high-frame-rate GUI acquisitions from overflowing the ESP32 frame
  pool by moving B-mode filtering/envelope processing to the visualization
  thread and throttling progress-widget and debug-log updates to 10 Hz.
- Kept GUI-compatible profiler saving out of the acquisition hot path by
  retaining received frame views and assembling the NPZ arrays after RX stops.
- Prevented finite GUI acquisitions from stalling when the device's continuous
  16-bit acquisition counter exceeds the requested frame count; received frames
  are stored using the GUI's independent sequential frame index.
- Worked around the Windows pySerial `SetCommState` error 31 affecting the
  ESP32-C6 USB Serial/JTAG CDC port while preserving all other configuration
  errors.
- Removed multi-second USB receive stalls by blocking for the first byte and
  then draining only the bytes already available from the serial driver.
- Prevented asynchronous `GET_DATA` frames from being mistaken for command
  acknowledgements, including during acquisition shutdown.
- Preserved partial serial writes and reported write timeouts instead of
  silently truncating protocol packets.

### Changed

- Packaged MSP430 releases as deterministic ZIPs with checksums, licenses, and
  the original TI runtime manifest and SPDX inventory.
- Added validated MSP430 ZIP uploads while retaining raw development formats.
- Updated the updater documentation, license notices, and ESP32 power warning.
- Renamed user-facing software branding from WULPUS PRO to WULPUS Pro Max.
- Renamed acquisition configuration APIs to `send_acq_config` without keeping
  the old method name.
- Renamed the main notebook to `wulpus_pro_example.ipynb`, made USB CDC its
  default transport, and moved older specialized notebooks to `legacy/`.
- Moved the ESP32 configuration widgets into `wulpus/device_config_gui.py`,
  arranged credential controls in a right-hand panel, and added explicit USB
  disconnect support.
- Renamed the BLE serial transport from `dongle.py` / `WulpusDongle` to `ble_dongle.py` / `WulpusBleDongle`.
- Decoupled `WulpusGuiSingleCh` from the BLE transport and made its device controls transport-neutral.
- Renamed the Wi-Fi transport and discovery APIs for WULPUS Pro Max and hardened TCP framing, command handling, connection cleanup, and acquisition lifecycle management.
- Reorganized `wulpus_pro_example.ipynb` to launch the GUI after explicit TX/RX and interactive ultrasound configuration, followed by the detailed manual Wi-Fi workflow.
- Added single-owner TCP/USB session arbitration to the ESP32 firmware while preserving the existing WULPUS wire protocol.
- Made the common framed-packet backlog and parser serve both command responses
  and acquisition data so packet boundaries remain synchronized.

### Removed

- Removed the legacy 8-channel WULPUS configuration, packet, and channel-GUI modules. This repository now exposes only the WULPUS Pro Max configuration stack.

## [0.1.0] - 2025-05-01

### Added

- GUI and library from WULPUS repository version 1.2.2
- A curve to the main GUI, visualizing the gain profile over time.

### Fixed

### Changed

- Extended the number of channels to 16.
- Modified TX/RX pin mapping.
- Added two new configuration parameters for VGA control:
    - `VGA Precharge time [cycles]`
    - `Wiper code for gain slope []`

- Extended the configuration package to accomodate two new parameters.

### Removed
- Removed `Capture restart time` and `Capture timeout time` from the old GUI.

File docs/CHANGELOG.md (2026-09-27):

# Changelog

All notable changes to the WULPUS Pro Max documentation will be documented in this file.

The format is based on [Keep a Changelog](https://keepachangelog.com/en/1.0.0/),
and this project adheres to [Semantic Versioning](https://semver.org/spec/v2.0.0.html).

## [Unreleased]

## [2.0.0] - 2026-09-27

### Added

- Added a user-facing firmware update guide for installing released ESP32 and
  MSP430 packages, with recovery and verification steps separated from the
  ESP32 implementation documentation.
- Added a comparison of the integrated WiFi host PCB, standalone XIAO
  ESP32-C6, and legacy nRF52 BLE host options.
- Documented persistent device configuration, reboot-only Wi-Fi policy,
  write-only credential commands, Wi-Fi runtime status, and the persistent
  Wi-Fi/TCP task model.
- Added WULPUS Pro Max full specifications as a dedicated documentation page.
- Added project-level documentation changelog.
- Added image documentation README with authorship and CC BY-ND 4.0 license information.
- Added PCB images to the root README hero and hardware photos sections.
- Added the system diagram to the root README.
- Documented native ESP32-C6 USB CDC operation, TCP/USB session arbitration,
  flashing and JTAG coexistence, binary-protocol logging constraints, and USB
  frame-rate profiling.

### Changed

- Updated the full specifications and README comparison with measured receive
  performance, data rates, power, mechanics, and arXiv sourcing.
- Renamed user-facing documentation from WULPUS PRO to WULPUS Pro Max and
  updated repository links for the new `wulpus-pro-max` name.
- Updated the WiFi host description and PRF specifications to document up to
  500 Hz over Wi-Fi/TCP or USB CDC, and replaced the outdated battery-charging
  status with external Adafruit battery support through a standard JST
  connector, USB charging, and integrated battery protection.
- Added the `images/v1_2` hardware photos, updated the root README gallery,
  captions and alt text, and extended image authorship coverage.
- Updated setup documentation to use `wulpus_pro_example.ipynb` as the main
  USB CDC, Wi-Fi, and BLE workflow and documented archived notebooks under
  `sw/legacy`.
- Documented GUI-compatible profiler NPZ output and the interactive NPZ
  viewer's file selection, configuration filtering, signal processing, and  replay controls.
- Moved the full specifications table from the root README to `docs/full_specifications.md`.
- Updated ESP32 and Python usage documentation for transport selection, USB
  connection ownership, and power-management behavior while a USB host is
  connected.
- Documented the task-based SPI DMA and packet-transmission architecture and
  runtime status commands.

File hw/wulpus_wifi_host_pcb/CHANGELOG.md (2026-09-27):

# Changelog

All notable changes to the WULPUS Pro Max WiFi Host PCB are documented in this
file.

The format is based on [Keep a Changelog](https://keepachangelog.com/en/1.0.0/),
and this project adheres to [Semantic Versioning](https://semver.org/spec/v2.0.0.html).

## [1.0.1] - 2026-09-21

### Changed

- Updated the schematic title blocks to use the WULPUS Pro Max product name.
- Updated the schematic sheet fields.
- Updated the PCB silkscreen.
- Regenerated the design files.

## [1.0.0] - 2026-08-22

### Added

- Initial release.

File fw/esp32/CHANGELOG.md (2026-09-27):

# Changelog

All notable changes to this project will be documented in this file.

The format is based on [Keep a Changelog](https://keepachangelog.com/en/1.0.0/),
and this project adheres to [Semantic Versioning](https://semver.org/spec/v2.0.0.html).

## [Unreleased]

## [1.2.0] - 2026-09-27

### Removed

- Dropped ESP32-C6-DEVKITM-1 evaluation kit support, including its board defaults
  and development setup instructions.

### Added

- Added ESP-IDF application-version and runtime MSP430-version reporting over
  the PC protocol, with the ESP32 release read from `firmware_version.txt` and
  required to match the firmware changelog, plus MSP430 discovery during the
  configuration SPI exchange. Reserved per-firmware Git hash fields and dirty
  flags for future build integration.
- Added MSP430FR5043 updates over USB/TCP with a 256 KiB staging partition,
  CRC-checked section images, boot-time four-wire JTAG programming/verification,
  persisted results and diagnostics, and XIAO JTAG GPIO defaults.
- Added the Python MSP430 updater, TI-TXT/Intel HEX import, `.mspfw` packaging,
  and a dedicated USB update notebook.
- Added versioned persistent device configuration, reboot-only Wi-Fi policy and
  credential commands, a persistent Wi-Fi manager, and connection-gated TCP.
- Added an ESP-IDF 6.0.1 toolchain guide covering EIM installation on Windows,
  Linux, and macOS, VS Code setup, manual installation, environment validation,
  flashing, and troubleshooting.
- Added structured ESP32 documentation for firmware threads and data/control
  paths, USB/TCP session switching, Wi-Fi provisioning, the MSP430 SPI and
  configuration protocol, and the framed ESP32-to-PC command/status protocol.
- Added native ESP32-C6 USB CDC as a wired WULPUS Pro Max command and RF-data transport.
- Added first-valid-command arbitration between concurrent TCP and USB listeners, including a `BUSY` response for the losing transport.
- Added a transport-neutral byte-stream layer with exact reads, complete writes, header prefetching, and packet-level TX locking.
- Added a fixed DMA-capable acquisition frame pool, sticky runtime error status,
  and `GET_STATUS`, `STATUS`, and `CLEAR_STATUS` protocol commands.

### Changed

- Renamed the user-facing ESP32 project branding from WULPUS PRO to WULPUS Pro
  Max. This naming change does not alter the existing ETH Zurich copyright,
  authorship, or license notices in inherited source files.
- Acquisition configuration now acknowledges after SPI success and reports
  transfer failures through `ERROR`; start/reset commands acknowledge after
  their actions. Acquisition configuration, start, and resets reject requests
  while the committed update is pending.
- Enabled TI-TXT export in the MSP430 CCS Debug configuration.
- Renamed the ESP acquisition command from `SET_CONFIG` to `SET_ACQ_CONFIG`
  while retaining wire ID `0x57` and without retaining the old command name.
- Made the TCP listener a persistent task gated by Wi-Fi connectivity and moved
  mDNS startup under the persistent Wi-Fi workflow.
- Corrected the documented MSP430 timer ordering: DC-DC turn-on precedes and
  therefore has a lower timer value than the acquisition period.
- Identified the WULPUS Pro Max WiFi host PCB, containing a XIAO ESP32-C6, as the
  primary firmware target throughout the documentation; standalone XIAO
  boards remain a development alternative.
- Increased the default DMA acquisition frame pool from 8 to 64 slots, giving
  128 ms of buffering at 500 FPS, and raised the configurable limit to 128.
- Moved command handling, MSP430 lifecycle management, and acquisition cleanup into one transport-independent session runner.
- Routed RF frames through the active session transport instead of the TCP socket directly.
- Reserved USB CDC for binary protocol data and disabled the conflicting application console by default.
- Prevented automatic light sleep whenever a USB host connection is detected,
  keeping enumeration and USB CDC communication responsive until physical
  disconnection.
- Started the USB listener before waiting for Wi-Fi provisioning or association,
  allowing wired operation when the network is unavailable or unconfigured.
- Split board access, frame storage, control state, protocol framing, generic
  links, and application threads into focused components.
- Made the acquisition thread the sole SPI readout owner and the packet TX
  thread the sole USB/TCP writer, isolating SPI DMA from link backpressure and
  prioritizing control responses at packet boundaries.
- Split the acquisition owner into focused command/state, scheduler,
  DATA_READY/SPI-handshake, and frame-ownership modules while retaining one
  task as the sole owner of MSP430 acquisition operations.
- Reduced `app_main()` to component initialization and task startup, and moved
  every application task implementation under `components/threads`.
- Expanded the firmware README with communication architecture, arbitration, USB flashing/JTAG coexistence, logging, and power-management behavior.

## [1.1.0] - 2026-08-22

### Fixed

- Matched the XIAO ESP32-C6 defaults to the WULPUS Pro Max Wi-Fi host PCB routing.

### Changed

- Replaced the dedicated host-ready handshake with MSP430 reset gating: the ESP32 now holds the MSP430 in reset until a TCP client connects and asserts reset again after disconnects or communication failures.
- Added a bounded graceful-shutdown handshake that sends the MSP430 restart command and waits for its post-`disableAll()` configuration request before asserting reset, with immediate reset retained as a timeout/error fallback.

### Removed

- Removed the dedicated host-ready GPIO configuration and output handling.

## [1.0.0] - 2026-07-11

### Added

- Added ESP32-C6 Wi-Fi firmware for using an ESP32 module as a WULPUS Pro Max host interface.
- Added support for the Seeed Studio XIAO ESP32-C6 board.
- Added board-specific defaults for the Seeed Studio XIAO ESP32-C6 and ESP32-C6-DEVKITM-1.
- Added Wi-Fi provisioning support for storing network credentials in non-volatile memory.
- Added mDNS-based local network discovery.
- Added MSP430 reset control from the ESP32 host firmware.
- Added power-management support for light-sleep operation when idle.
- Added WULPUS PRO connector pin mapping documentation for supported ESP32-C6 boards.
- Added Python-side Wi-Fi usage documentation through `../../sw/wulpus_pro_example.ipynb`.

### Fixed

- Fixed the ESP32-C6-DEVKITM-1 defaults so `MSP_RST_N` no longer conflicts with SPI MOSI on GPIO2.

### Changed

- Updated the project to ESP-IDF 6.0.1.
- Refactored ESP-IDF configuration into reusable project defaults, target-specific defaults, and board-specific defaults.
- Documented first-time Wi-Fi provisioning after flashing the firmware.
- Documented tested board variants, board selection, build, flash, and serial-port usage.

### Removed

- Removed the old ESP32-C6-DEVKITM-1 reset mapping from GPIO2; `MSP_RST_N` is now mapped to GPIO3 for that board.

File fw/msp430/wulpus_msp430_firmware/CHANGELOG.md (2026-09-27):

# Changelog

All notable changes to this project will be documented in this file.

The format is based on [Keep a Changelog](https://keepachangelog.com/en/1.0.0/),
and this project adheres to [Semantic Versioning](https://semver.org/spec/v2.0.0.html).

## [Unreleased]

## [1.1.0] - 2026-09-27

### Added

- Added a compiled semantic version returned to the host MCU during the existing
  full-duplex SPI transaction.

## [1.0.0]

### Changed

- Removed the P5.7 host-ready polling gate. The ESP32 host now keeps the MSP430 in reset until a TCP client connects.

## [0.1.0] - 2025-05-01

### Added

- MSP 430 firmware from WULPUS repository version 1.2.2

### Fixed

### Changed

- Changed pin mapping of the pins according to the schematics of the WULPUS PRO
- Added initialization of multiple new IOs for enbaling power domain and VGA control
- Added two new configuration parameters to the `msp_config` for VGA control:
    - `VGA Precharge time`
    - `Wiper code for gain slope`

- Added a new timer instance for precise time delay for VGA control input precharging.

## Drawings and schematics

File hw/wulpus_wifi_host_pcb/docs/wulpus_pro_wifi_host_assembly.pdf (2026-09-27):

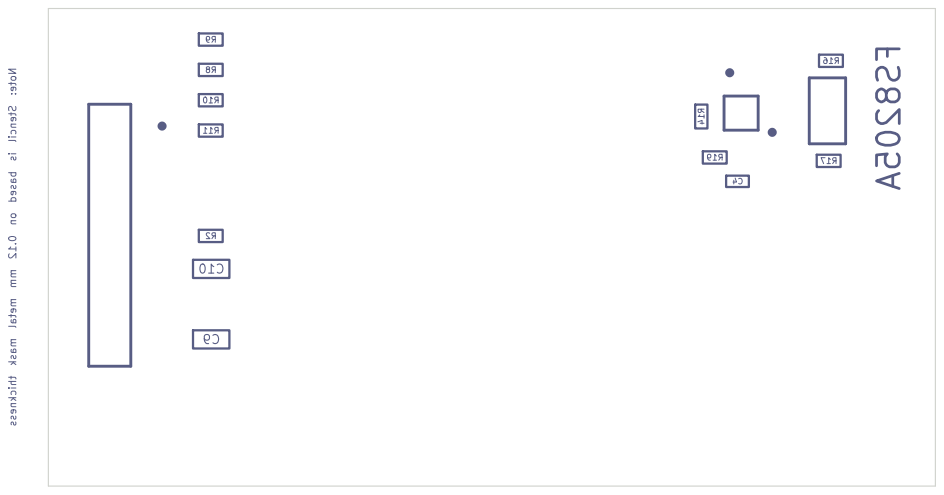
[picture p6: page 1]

Sheet:
File: wulpus_pro_wifi_host.kicad_pcb
Title: WULPUS Pro Max WiFi host

Size: A4 | Rev: v1.0.1
KiCad E.D.A. 10.0.3 | Id: 1/3

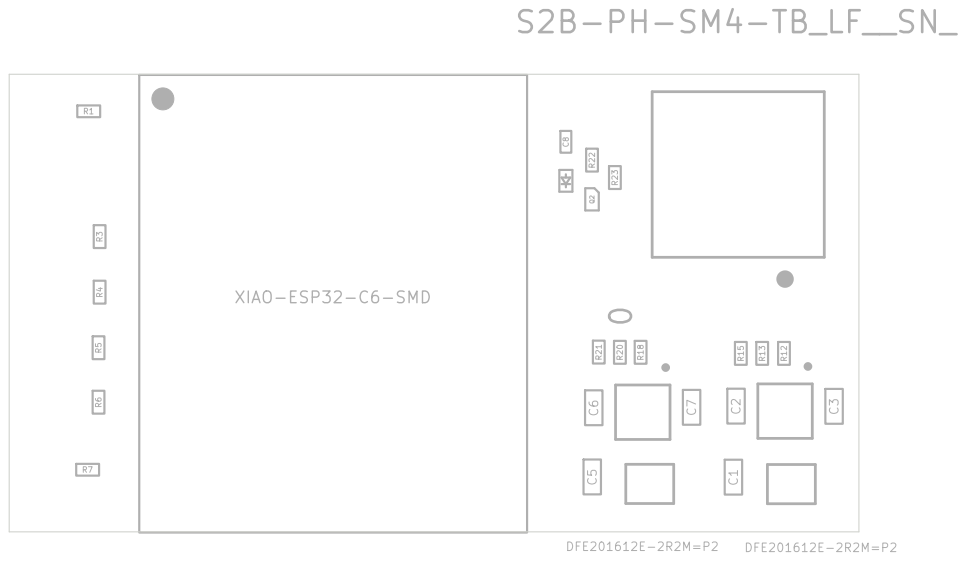
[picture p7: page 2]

Sheet:
File: wulpus_pro_wifi_host.kicad_pcb
Title: WULPUS Pro Max WiFi host

AB

C

D

AB

C

D Date: 2026-09-21

### Title: WULPUS Pro Max WiFi host

File: wulpus_pro_wifi_host.kicad_pcb

Sheet:

Reviewer: Cedric Hirschi

Author: Sergei Vostrikov

## BOARD CHARACTERISTICS

Copper layer count: | 4 | Board thickness: | 0.9820 mm
Board overall dimensions: | 39.0000 mm x 21.0000 mm
Min track/spacing: | 0.2000 mm / 0.1400 mm | Min hole diameter: | 0.3000 mm
Copper finish: | None | Impedance control: | No
Castellated pads: | No | Press-fit pads: | No
Plated board edge: | No | Edge card connectors: No
Layer Name | Type | Material | Thickness | Color | Epsilon R | Loss Tangent
F.Silkscreen | Top silk screen | Not specified | Not specified | White | 1 | 0
F.Paste | Top solder paste | | Not specified | | 1 | 0
F.Mask | Top solder mask | Not specified | 0.01 mm | Black | 3.3 | 0
F.Cu | Copper | | 0.035 mm | | 1 | 0
Dielectric 1 | Prepreg | S1000HB | 0.196 mm | Not specified | 4.74 | 0.02
In1.Cu | Copper | | 0.035 mm | | 1 | 0
Dielectric 2 | Core | S1000H | 0.43 mm | Not specified | 4.6 | 0.02
In2.Cu | Copper | | 0.035 mm | | 1 | 0
Dielectric 3 | Prepreg | S1000HB | 0.196 mm | Not specified | 4.74 | 0.02
B.Cu | Copper | | 0.035 mm | | 1 | 0
B.Mask | Bottom solder mask | Not specified | 0.01 mm | Black | 3.3 | 0
B.Paste | Bottom solder paste | | Not specified | | 1 | 0
B.Silkscreen | Bottom silk screen | Not specified | Not specified | White | 1 | 0

39 21

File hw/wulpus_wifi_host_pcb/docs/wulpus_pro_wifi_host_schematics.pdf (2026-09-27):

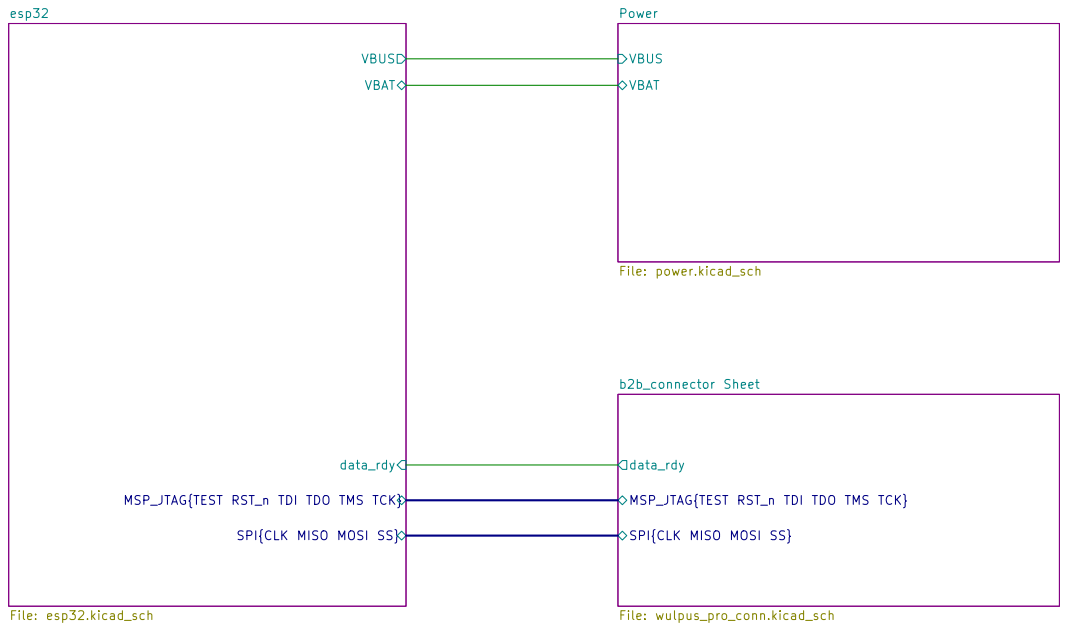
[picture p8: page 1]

esp32
data_rdy VBAT SPI{CLK MISO MOSI SS}

VBAT VBUS Power File: power.kicad_sch

MSP_JTAG{TEST RST_n TDI TDO TMS TCK} VBUS

MSP_JTAG{TEST RST_n TDI TDO TMS TCK}

SPI{CLK MISO MOSI SS}

Sheet: /
File: wulpus_pro_wifi_host.kicad_sch
Title: WULPUS Pro Max WiFi host

Size: A4 | Rev: v1.0.1
KiCad E.D.A. 10.0.3 | Id: 1/4

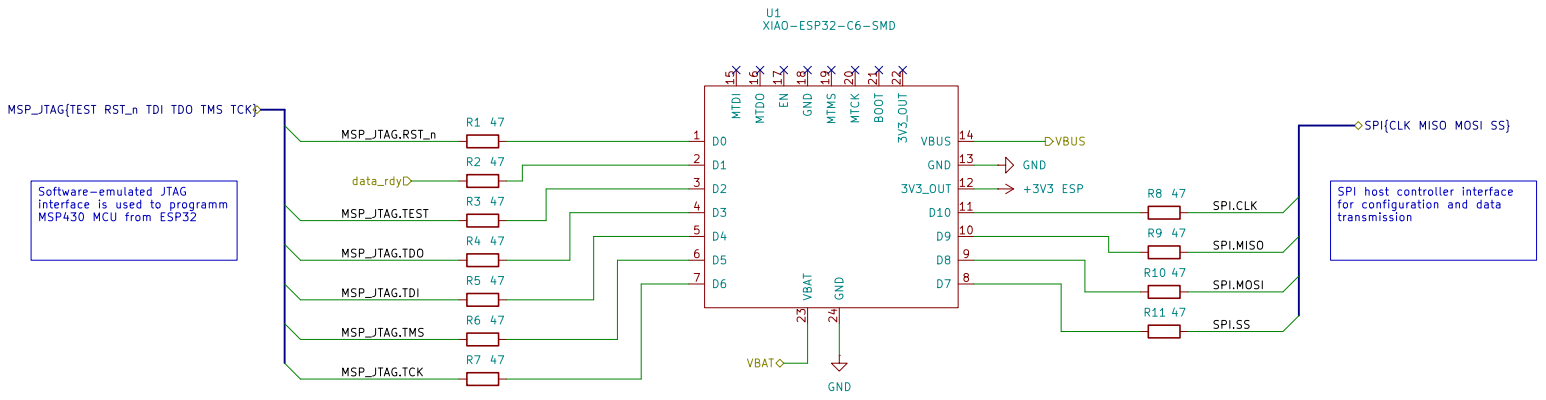
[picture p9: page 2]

VBUS MSP_JTAG{TEST RST_n TDI TDO TMS TCK}

transmission Software-emulated JTAG
interface is used to programm
MSP430 MCU from ESP32

for configuration and data

Sheet: /esp32/
File: esp32.kicad_sch
Title: WULPUS Pro Max WiFi host

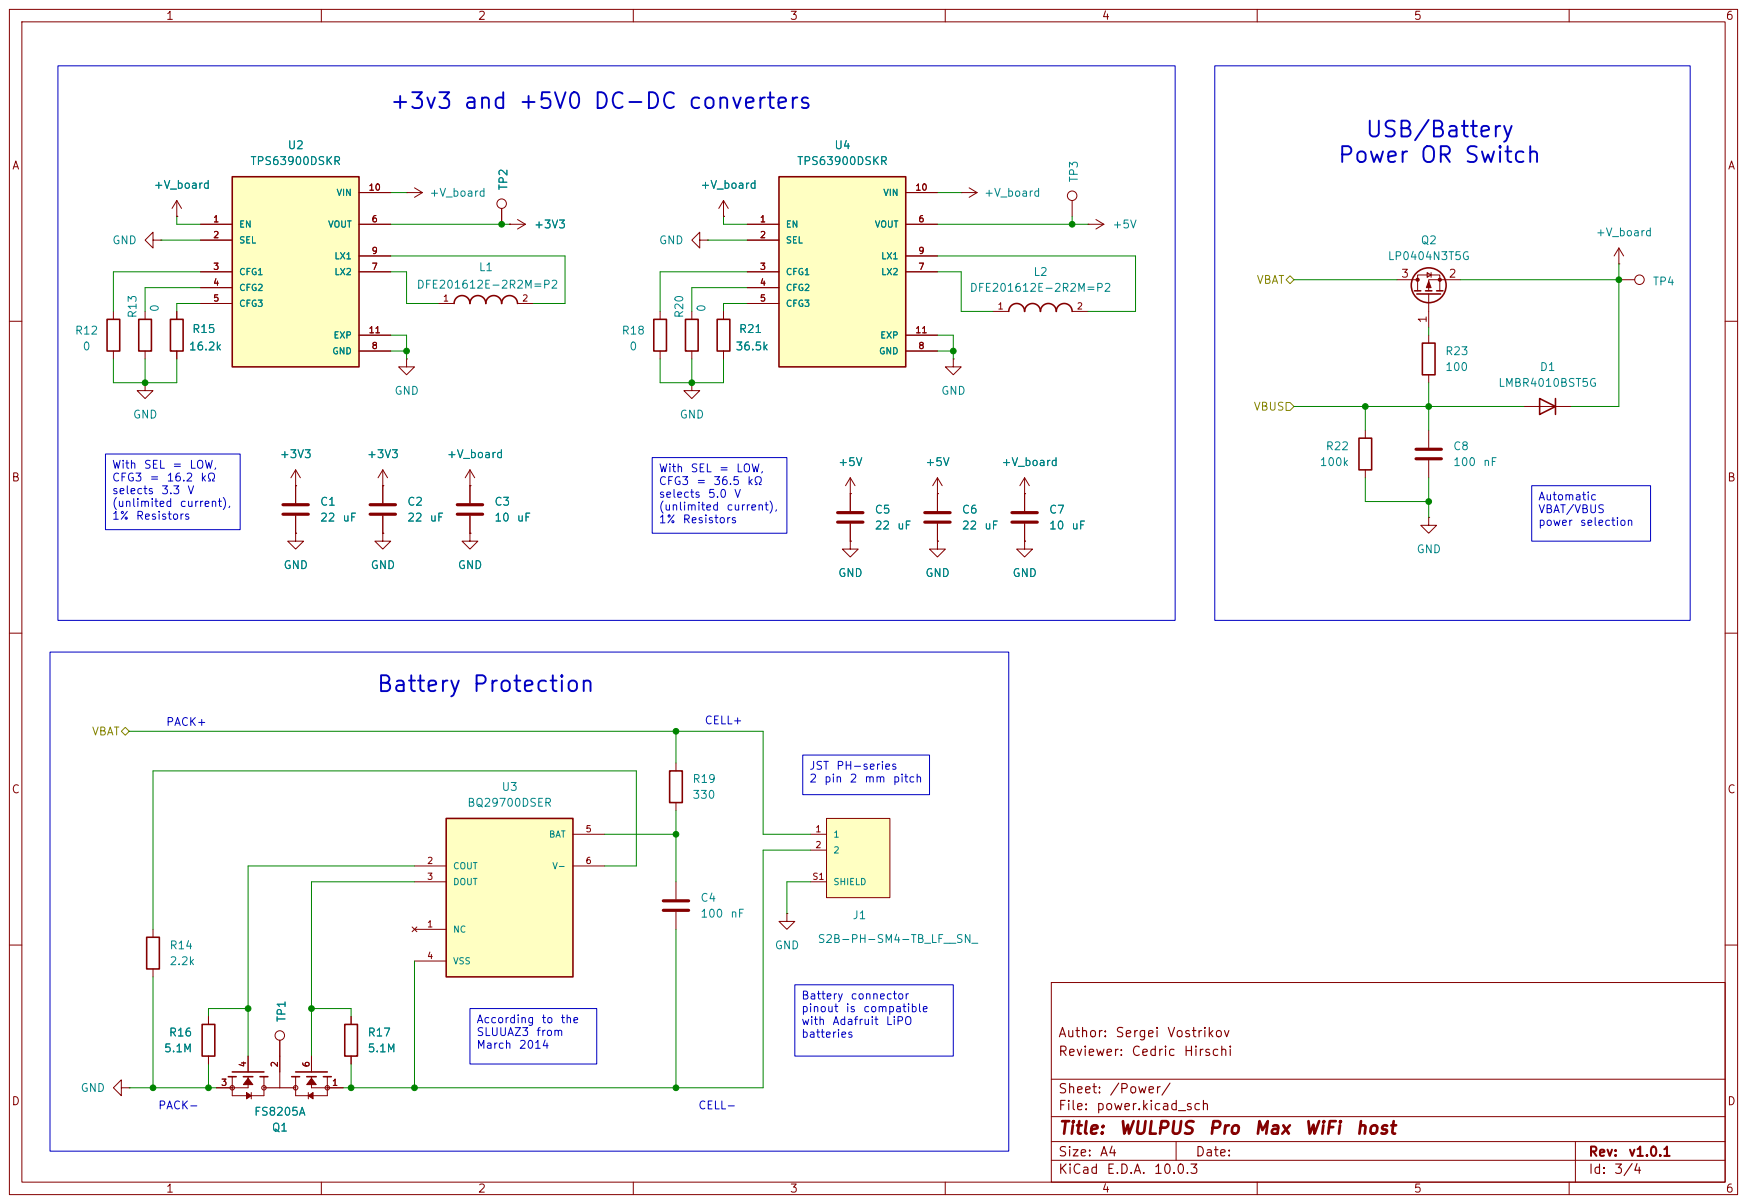
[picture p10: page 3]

(unlimited current), 1% Resistors With SEL = LOW, CFG3 = 16.2 kΩ

power selection With SEL = LOW, CFG3 = 36.5 kΩ

JST PH-series 2 pin 2 mm pitch

Battery connector pinout is compatible with Adafruit LiPO

Sheet: /Power/
File: power.kicad_sch
Title: WULPUS Pro Max WiFi host

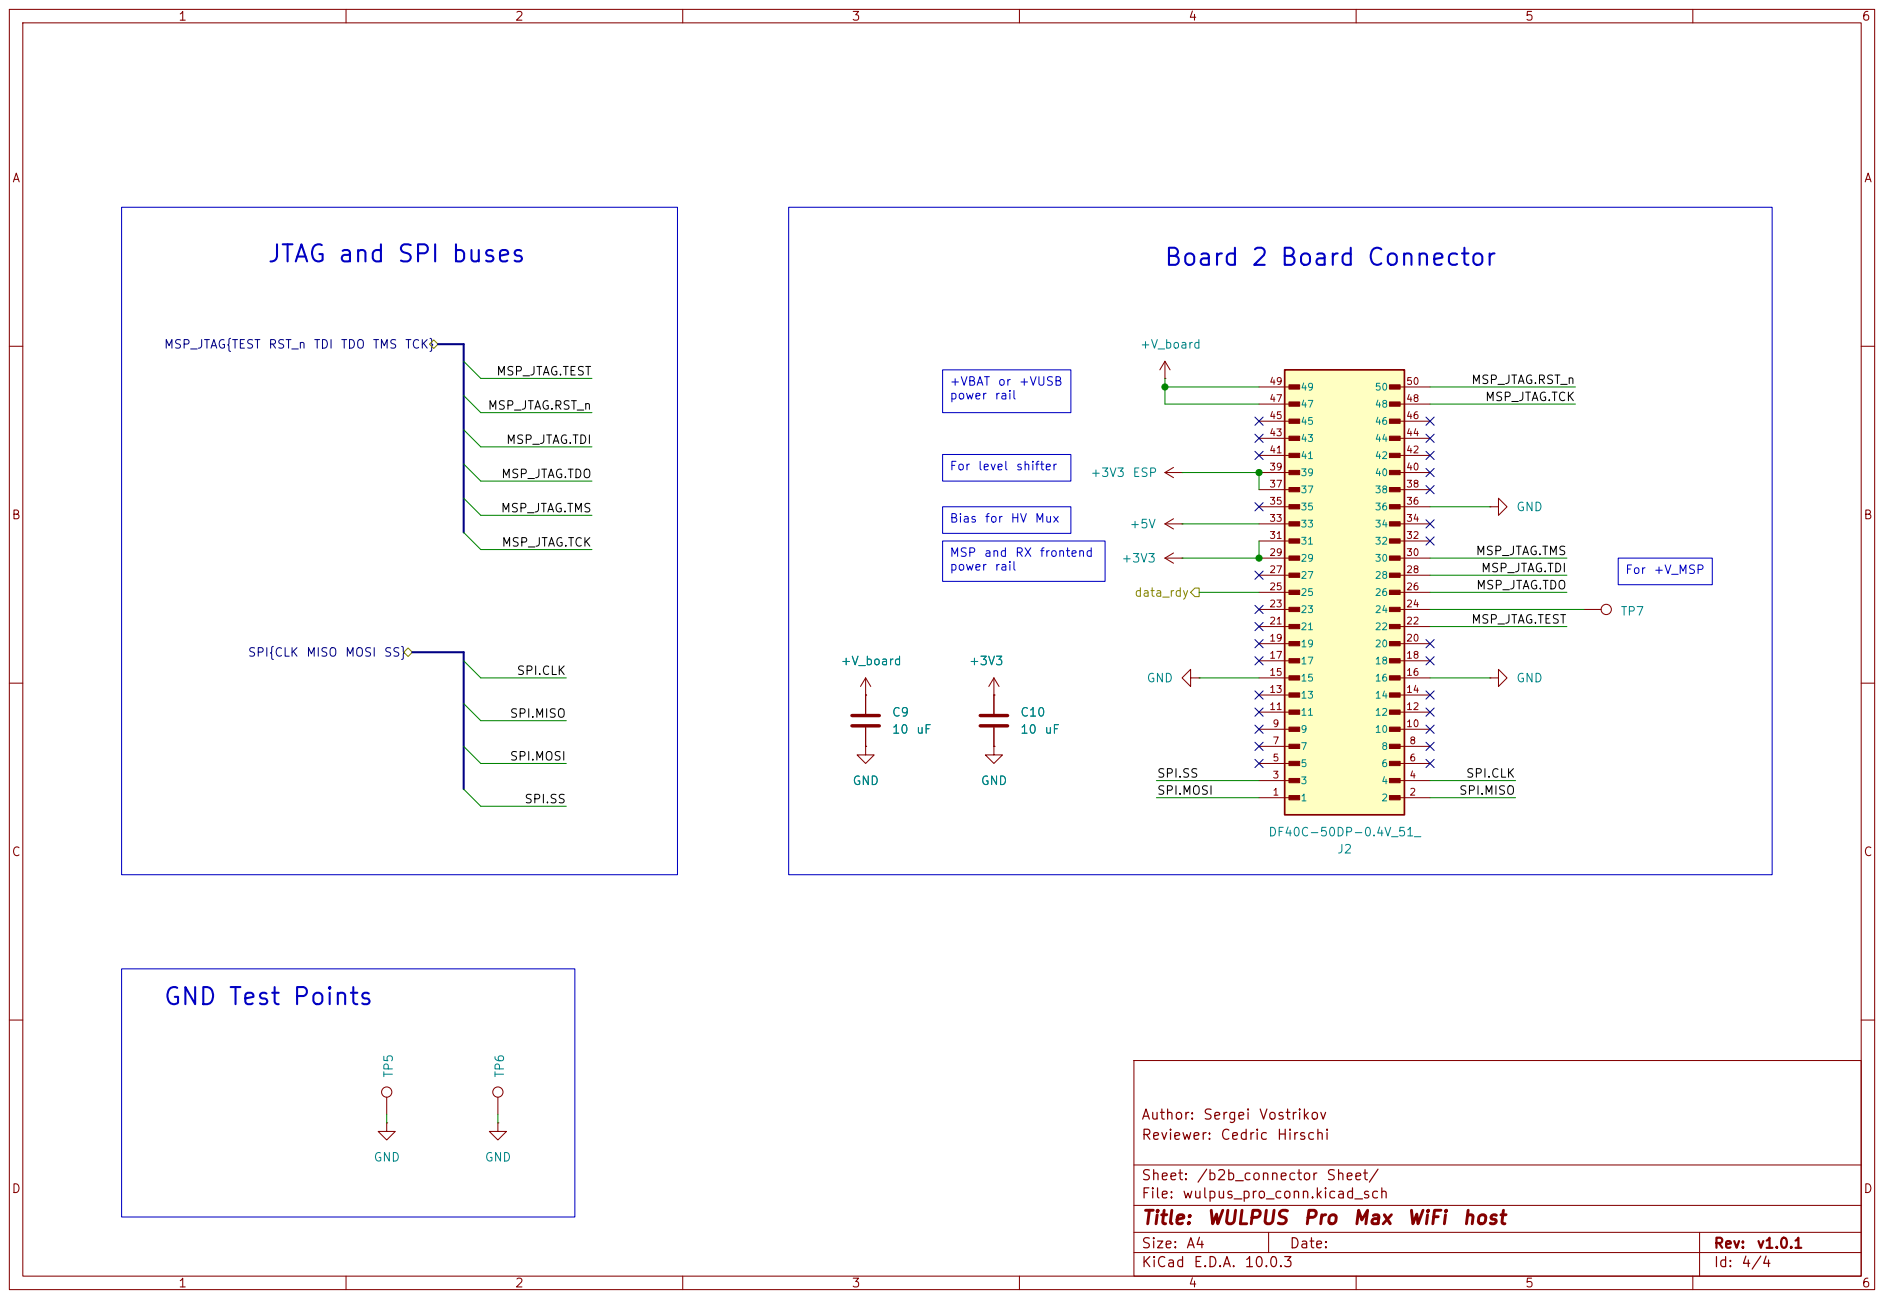
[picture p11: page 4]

power rail JTAG and SPI buses

MSP_JTAG{TEST RST_n TDI TDO TMS TCK}

SPI.CLK MSP_JTAG.TCK MSP_JTAG.TDO

For level shifter Bias for HV Mux MSP and RX frontend

Sheet: /b2b_connector Sheet/
File: wulpus_pro_conn.kicad_sch
Title: WULPUS Pro Max WiFi host

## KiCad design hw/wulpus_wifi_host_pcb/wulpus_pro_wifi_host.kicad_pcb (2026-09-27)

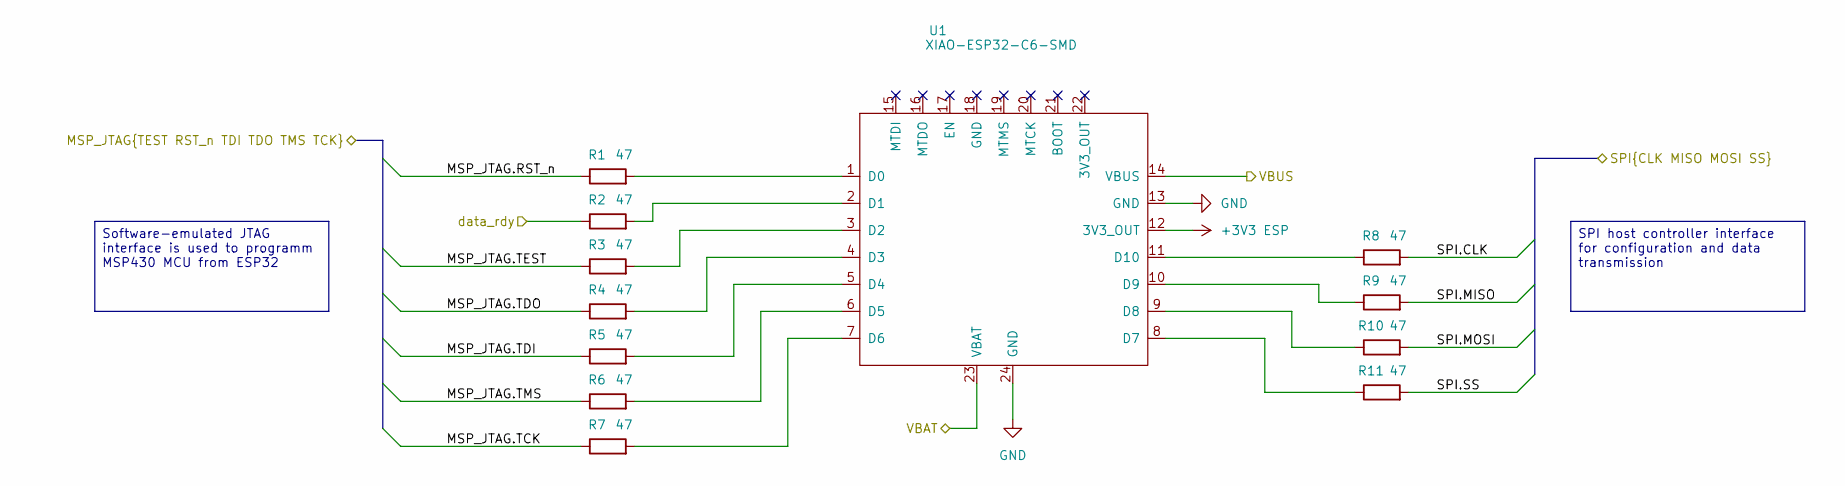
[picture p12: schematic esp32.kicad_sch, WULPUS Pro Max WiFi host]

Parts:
R1, R2, R3, R4, R5, R6, R7, R8, R9, R10, R11: 47; R_0402_1005Metric
U1: XIAO-ESP32-C6-SMD

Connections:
+3V3 ESP: U1.12 (3V3_OUT); also elsewhere on the board
/Power/VBAT: U1.23 (VBAT); also elsewhere on the board
/Power/VBUS: U1.14 (VBUS); also elsewhere on the board
/b2b_connector Sheet/MSP_JTAG.RST_n: R1.1; also elsewhere on the board
/b2b_connector Sheet/MSP_JTAG.TCK: R7.1; also elsewhere on the board
/b2b_connector Sheet/MSP_JTAG.TDI: R5.1; also elsewhere on the board
/b2b_connector Sheet/MSP_JTAG.TDO: R4.1; also elsewhere on the board
/b2b_connector Sheet/MSP_JTAG.TEST: R3.1; also elsewhere on the board
/b2b_connector Sheet/MSP_JTAG.TMS: R6.1; also elsewhere on the board
/b2b_connector Sheet/SPI.CLK: R8.2; also elsewhere on the board
/b2b_connector Sheet/SPI.MISO: R9.2; also elsewhere on the board
/b2b_connector Sheet/SPI.MOSI: R10.2; also elsewhere on the board
/b2b_connector Sheet/SPI.SS: R11.2; also elsewhere on the board
/b2b_connector Sheet/data_rdy: R2.1; also elsewhere on the board
GND: U1.13 (GND), U1.24 (GND); also elsewhere on the board
unnamed: R1.2, U1.1 (D0)
unnamed: R2.2, U1.2 (D1)
unnamed: R3.2, U1.3 (D2)
unnamed: R4.2, U1.4 (D3)
unnamed: R5.2, U1.5 (D4)
unnamed: R6.2, U1.6 (D5)
unnamed: R7.2, U1.7 (D6)
unnamed: R11.1, U1.8 (D7)
unnamed: R10.1, U1.9 (D8)
unnamed: R9.1, U1.10 (D9)
unnamed: R8.1, U1.11 (D10)

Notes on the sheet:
Software-emulated JTAG interface is used to programm MSP430 MCU from ESP32
SPI host controller interface for configuration and data transmission

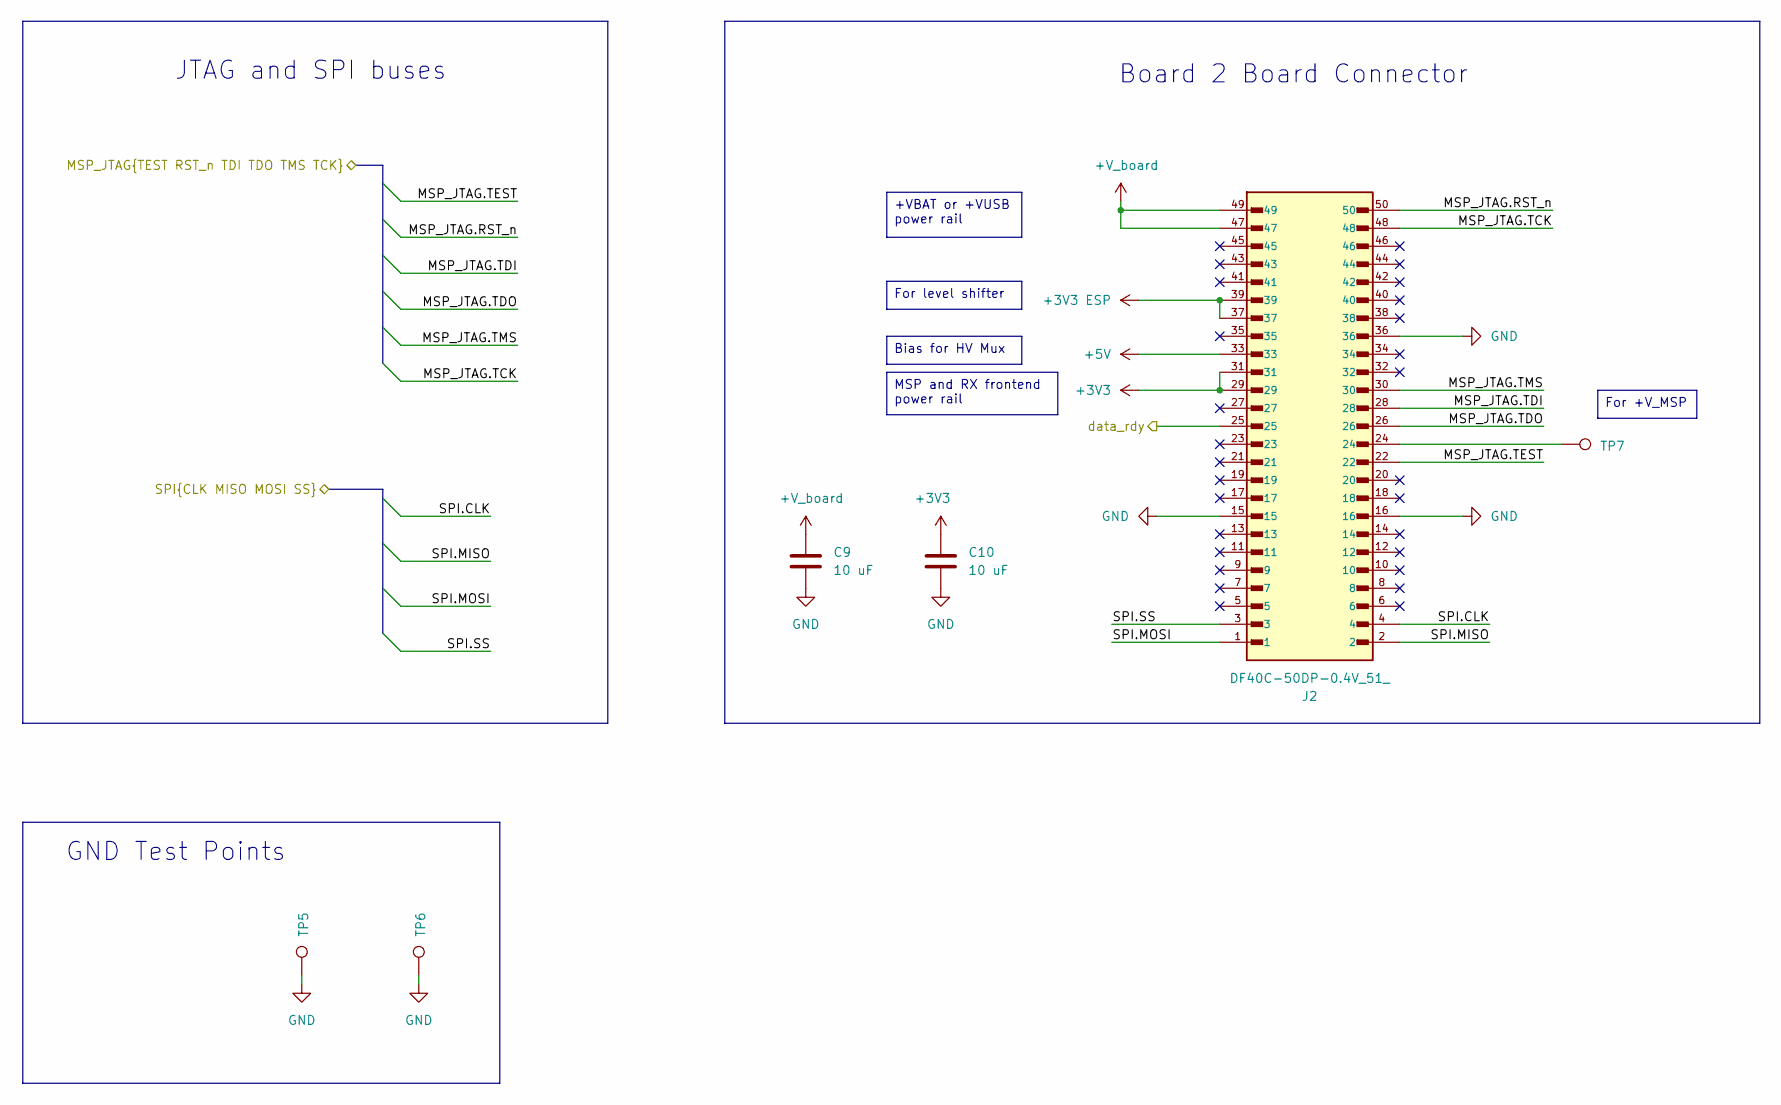
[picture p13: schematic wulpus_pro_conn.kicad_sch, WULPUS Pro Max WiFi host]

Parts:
C9, C10: 10 uF; C_0603_1608Metric
J2: DF40C-50DP-0.4V_51_; HIROSE_DF40C-50DP-0.4V_51_; PARTREV 2
TP5, TP6, TP7: TestPoint; TestPoint_Pad_1.0x1.0mm

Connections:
+3V3: C10.1, J2.29, J2.31; also elsewhere on the board
+3V3 ESP: J2.37, J2.39; also elsewhere on the board
+5V: J2.33; also elsewhere on the board
+V_board: C9.1, J2.47, J2.49; also elsewhere on the board
/b2b_connector Sheet/MSP_JTAG.RST_n: J2.50; also elsewhere on the board
/b2b_connector Sheet/MSP_JTAG.TCK: J2.48; also elsewhere on the board
/b2b_connector Sheet/MSP_JTAG.TDI: J2.28; also elsewhere on the board
/b2b_connector Sheet/MSP_JTAG.TDO: J2.26; also elsewhere on the board
/b2b_connector Sheet/MSP_JTAG.TEST: J2.22; also elsewhere on the board
/b2b_connector Sheet/MSP_JTAG.TMS: J2.30; also elsewhere on the board
/b2b_connector Sheet/SPI.CLK: J2.4; also elsewhere on the board
/b2b_connector Sheet/SPI.MISO: J2.2; also elsewhere on the board
/b2b_connector Sheet/SPI.MOSI: J2.1; also elsewhere on the board
/b2b_connector Sheet/SPI.SS: J2.3; also elsewhere on the board
/b2b_connector Sheet/data_rdy: J2.25; also elsewhere on the board
GND: C9.2, C10.2, J2.15, J2.16, J2.36, TP5.1 (1_1), TP6.1 (1_1); also elsewhere on the board
unnamed: J2.24, TP7.1 (1_1)

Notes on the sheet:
JTAG and SPI buses
Board 2 Board Connector
GND Test Points
For +V_MSP
For level shifter
Bias for HV Mux
MSP and RX frontend power rail
+VBAT or +VUSB power rail

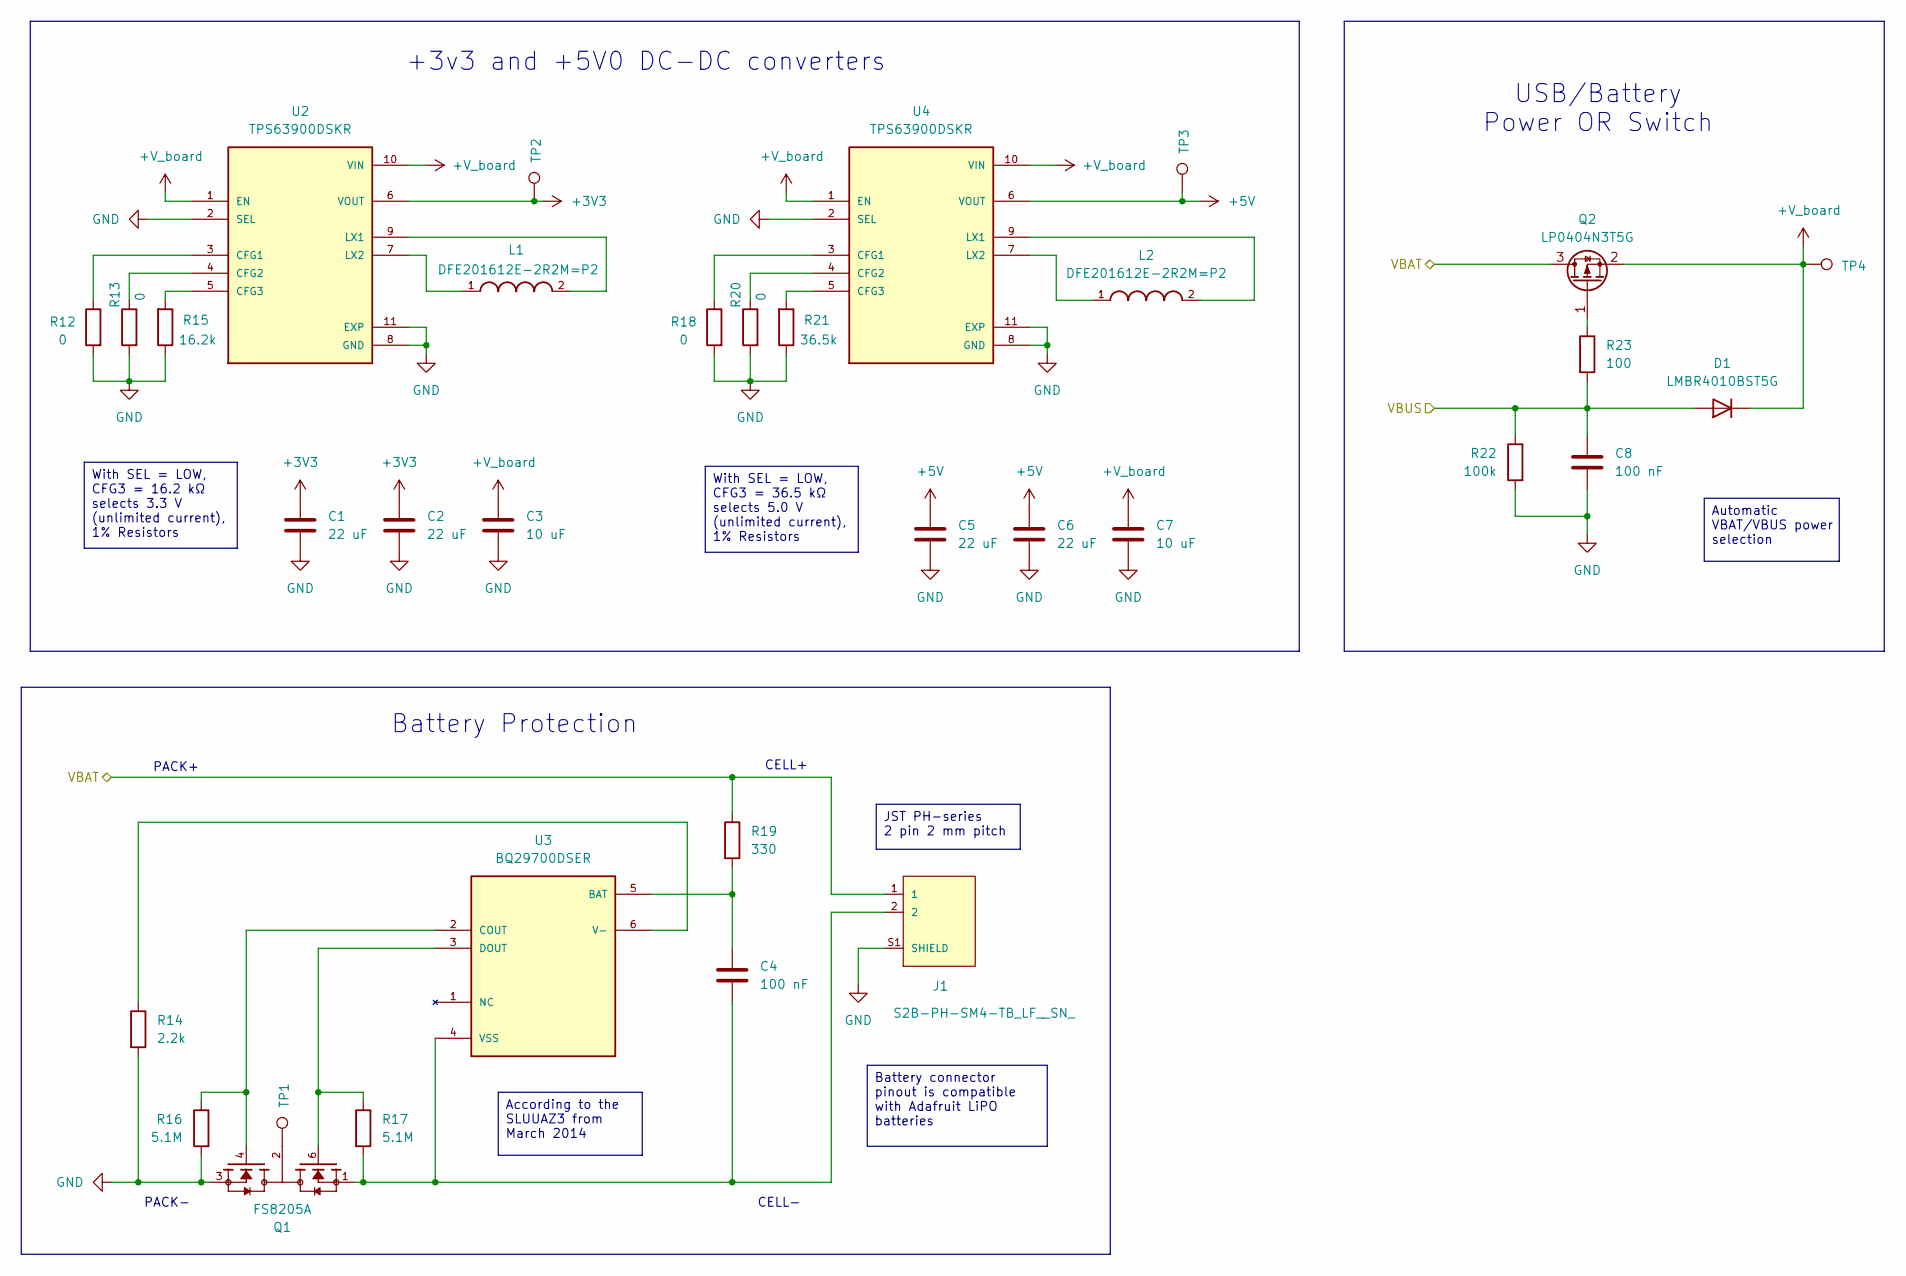
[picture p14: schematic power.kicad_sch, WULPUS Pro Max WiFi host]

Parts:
C1, C2, C5, C6: 22 uF; C_0603_1608Metric
C3, C7: 10 uF; C_0603_1608Metric
C4, C8: 100 nF; C_0402_1005Metric
D1: LMBR4010BST5G; D_SOD-882
J1: S2B-PH-SM4-TB_LF__SN_; JST_S2B-PH-SM4-TB_LF__SN_
L1, L2: DFE201612E-2R2M=P2; INDC2016X120N
Q1: FS8205A; SOT95P280X145-6N; PARTREV 1.9
Q2: LP0404N3T5G; SOT-883
R12, R13, R18, R20: 0; R_0402_1005Metric
R14: 2.2k; R_0402_1005Metric
R15: 16.2k; R_0402_1005Metric
R16, R17: 5.1M; R_0402_1005Metric
R19: 330; R_0402_1005Metric
R21: 36.5k; R_0402_1005Metric
R22: 100k; R_0402_1005Metric
R23: 100; R_0402_1005Metric
TP1, TP2, TP3, TP4: TestPoint; TestPoint_Pad_1.0x1.0mm
U2, U4: TPS63900DSKR; IC_TPS63900DSKR; PARTREV D
U3: BQ29700DSER; SON50P150X150X80-6N; PARTREV G

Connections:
+3V3: C1.1, C2.1, TP2.1 (1_1), U2.6 (VOUT); also elsewhere on the board
+5V: C5.1, C6.1, TP3.1 (1_1), U4.6 (VOUT); also elsewhere on the board
+V_board: C3.1, C7.1, D1.1 (K), Q2.2 (S), TP4.1 (1_1), U2.1 (EN), U2.10 (VIN), U4.1 (EN), U4.10 (VIN); also elsewhere on the board
/Power/VBAT: J1.1, Q2.3 (D), R19.1; also elsewhere on the board
/Power/VBUS: C8.1, D1.2 (A), R22.1, R23.2; also elsewhere on the board
GND: C1.2, C2.2, C3.2, C5.2, C6.2, C7.2, C8.2, J1.S1 (SHIELD), J1.S2 (SHIELD), Q1.3, R12.2, R13.2, R14.2, R15.1, R16.2, R18.2, R20.2, R21.1, R22.2, U2.2 (SEL), U2.8 (GND), U2.11 (EXP), U2.14, U2.15, U4.2 (SEL), U4.8 (GND), U4.11 (EXP), U4.14, U4.15; also elsewhere on the board
unnamed: Q1.2, Q1.5, TP1.1 (1_1)
unnamed: Q2.1 (G), R23.1
unnamed: R12.1, U2.3 (CFG1)
unnamed: R13.1, U2.4 (CFG2)
unnamed: R15.2, U2.5 (CFG3)
unnamed: L1.2, U2.9 (LX1)
unnamed: L1.1, U2.7 (LX2)
unnamed: C4.1, R19.2, U3.5 (BAT)
unnamed: Q1.4, R16.1, U3.2 (COUT)
unnamed: Q1.6, R17.1, U3.3 (DOUT)
unnamed: R14.1, U3.6 (V-)
unnamed: C4.2, J1.2, Q1.1, R17.2, U3.4 (VSS)
unnamed: R18.1, U4.3 (CFG1)
unnamed: R20.1, U4.4 (CFG2)
unnamed: R21.2, U4.5 (CFG3)
unnamed: L2.2, U4.9 (LX1)
unnamed: L2.1, U4.7 (LX2)

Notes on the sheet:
CELL-
PACK-
Battery Protection
CELL+
PACK+
+3v3 and +5V0 DC-DC converters
USB/Battery Power OR Switch
With SEL = LOW, CFG3 = 16.2 kΩ selects 3.3 V (unlimited current), 1% Resistors
According to the SLUUAZ3 from March 2014
Battery connector pinout is compatible with Adafruit LiPO batteries
Automatic VBAT/VBUS power selection
With SEL = LOW, CFG3 = 36.5 kΩ selects 5.0 V (unlimited current), 1% Resistors
JST PH-series 2 pin 2 mm pitch

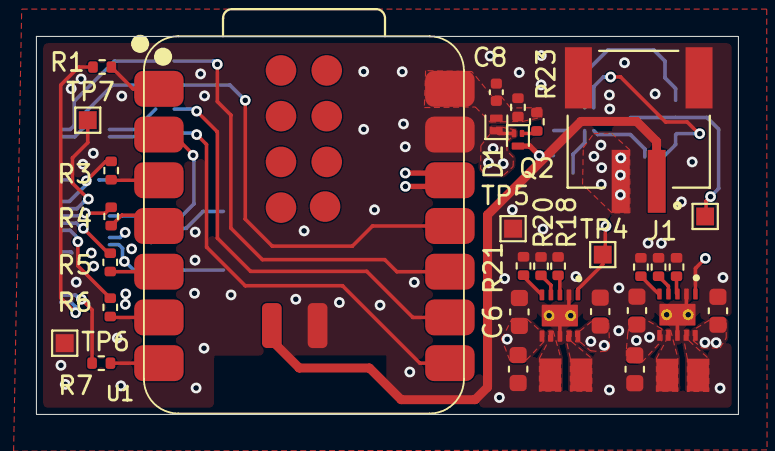
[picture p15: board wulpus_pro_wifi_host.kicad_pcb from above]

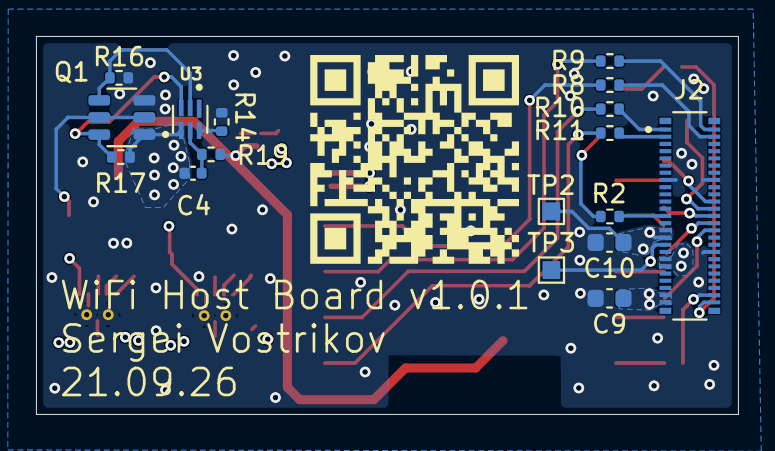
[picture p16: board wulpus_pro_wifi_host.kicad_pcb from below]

Board: 4 copper layers, 39.0 x 21.0 mm, 52 parts (18 on the bottom side), 47 nets.

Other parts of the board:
QR*****: https://github.com/Sergio5714/wulpus-pro; wulpus_pro_qr

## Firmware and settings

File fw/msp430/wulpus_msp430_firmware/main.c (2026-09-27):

/*
 * Copyright (C) 2025 ETH Zurich. All rights reserved.
 *
 * Author: Sergei Vostrikov, ETH Zurich
 *
 * Licensed under the Apache License, Version 2.0 (the "License");
 * you may not use this file except in compliance with the License.
 * You may obtain a copy of the License at
 *
 *      http://www.apache.org/licenses/LICENSE-2.0
 *
 * Unless required by applicable law or agreed to in writing, software
 * distributed under the License is distributed on an "AS IS" BASIS,
 * WITHOUT WARRANTIES OR CONDITIONS OF ANY KIND, either express or implied.
 * See the License for the specific language governing permissions and
 * limitations under the License.
 * 
 * SPDX-License-Identifier: Apache-2.0
 */

#include <msp430.h> 
#include "firmware_version.h"
#include "wulpus_sys.h"

#include "uslib_timers_isrs.h"

//// LOCAL MACRO DEFINITIONS AND VARIABLES ////

// First two Bytes of the measurement header
// Used to indicate the start of an US frame
#define MEAS_START_OF_FRAME_MASK 0xFF
// US measurement header
static uint8_t meas_header[4] = {0};
static uint16_t meas_frame_nr = 0;

// Empty config with MSP settings for US acquisition
msp_config_t msp_config;

// TX RX active config ID
uint8_t tx_rx_id = 0;

// VGA fixed gain mode flag
uint8_t vga_fixed_gain = 1;

// Firmware metadata shifted out while the ESP32 sends an acquisition config.
// The hash and dirty-state extension is reserved for future build integration.
static const uint8_t firmware_hello[8] = {
    'W', 'V', 'E', 'R', WULPUS_MSP_FW_HELLO_VERSION,
    WULPUS_MSP_FW_VERSION_MAJOR,
    WULPUS_MSP_FW_VERSION_MINOR,
    WULPUS_MSP_FW_VERSION_PATCH,
};

// A routine to get configuration package from nRF
static void getConfigPack(void);

// High level functions used in main
static void configAfterPowerUp(void);
static void receiveUssConfPackage(void);
static void usAcquisitionLoop(void);

// Callbacks implementation
static void hsPllUnlockCallback(void);
static void saphSeqAcqDoneCallback(void);
static void slowTimerCc2Callback(void);
static void fastTimerCc0Callback(void);
static void fastTimerCc2Callback(void);

int main(void)
{

    // Disable the GPIO power-on default high-impedance mode to activate
    // previously configured port settings
    PMM_unlockLPM5();

    // Initial configuration
    // Sets default parameters
    configAfterPowerUp();

    while(1)
    {
        // Set default parameters
        tx_rx_id = 0;
        meas_frame_nr = 0;

        // WULPUS PRO (17.04.25)
        // Pause Timer Slow Software Events
        pauseTimerSlowSwEvents();
        disableAll();


        // Receive Uss configuration package from nRF
        receiveUssConfPackage();

        // Configure Uss according to the new package
        confUsSubsystem();

        // Configure envelope extractor
        if (msp_config.enEnvDetector)
        {
            enableEnvDet();
        }
        else
        {
            disableEnvDet();
        }

        // Configure the events of slow and fast timers
        confTimerSlowSwEvents();
        confTimerFastSwEvents();

//        // Power up HV PCB
//        enableHvPcbSupply();
//        // Enable Power for OPA836
//        enableOpAmpSupply();

        // WULPUS PRO (17.04.25)
        enableAll();

        // Enter acquisition loop
        usAcquisitionLoop();

    }
    // Not reachable
	
	return 0;
}

void configAfterPowerUp(void)
{

    // Initialize DMA for SPI transfers and SPI for
    // nRF <-> MSP and MSP <-> HV MUX communication
    usDmaInit();
    usSpiInit();
    hvMuxInit();

    // Initialize board GPIOs
    initOtherGpios();
    // Init power switches
    initAllPowerSwitches();

    // Get default Ultrasound config
    getDefaultUsConfig(&msp_config);

    // Update the internal config of the ultrasound library
    setNewUsConfig(&msp_config);

    // Init timers
    timerSlowInit();
    timerFastInit();
    timerUsDelayInit();

    // Hook timers-related callback

    // Timer Slow CC2 callback enables HV DC-DC and opAmp
    TIMER_SLOW_CCR2_CALLBACK = &slowTimerCc2Callback;
    // Timer Slow CC0 callback reloads parameters of the capture
    // such as measurement period and dc-dc turn on time
    TIMER_SLOW_CCR0_CALLBACK = &reloadTimerSlowSwEvents;

    // Timer Fast CC1 callback triggers acquisition and
    // enables CC0 interrupt
    TIMER_FAST_CCR1_CALLBACK = &triggerAcqTimerFastEvent;
    // Timer Fast CC0 callback switches HV MUX to receive,
    // stops the DC-DC converter and the Fast timer
    TIMER_FAST_CCR0_CALLBACK = &fastTimerCc0Callback;
    // Timer Fast CC2 callback Enables VGA gain RC network
    TIMER_FAST_CCR2_CALLBACK = &fastTimerCc2Callback;

    // Hook other callbacks
    HS_PLL_UNLOCK_CALLBACK = &hsPllUnlockCallback;
    SAPH_SEQ_ACQ_DONE_CALLBACK = &saphSeqAcqDoneCallback;

    // Configure Ultrasound peripherals
    confUsSubsystem();

    // Configure the events of slow and fast timers
    confTimerSlowSwEvents();
    confTimerFastSwEvents();

    return;
}

static void receiveUssConfPackage(void)

{
    while(1)
    {
        // Sleep for 10 ms
        timerSlowDelay(327, LPM3_bits);

        // The host only releases MSP430 reset after a client connects.
        getConfigPack();

        // Process received package and update Uss config
        if (extractUsConfig(usSpiGetRxPtr(), &msp_config))
        {
            // Update Ultrasound config
            setNewUsConfig(&msp_config);
            return;
        }
    }
}

static void usAcquisitionLoop(void)
{

    bool no_error = true;

    while(1)
    {
            // Update the measurement header
            meas_header[0] = MEAS_START_OF_FRAME_MASK;
            meas_header[1] = tx_rx_id;
            meas_header[2] = (uint8_t) (meas_frame_nr & 0xFF);
            meas_header[3] = (uint8_t) (meas_frame_nr >> 8);
            memcpy((uint16_t *) 0x4000, &meas_header, 4);


            // Configure VGA Gain Settings

            timerUsDelayStart();
            if (msp_config.vgaRcPrechargeCycles != 0)
            {
                // Set 100 k
                vgaDigipotSetWiperCode(0);
                vgaDigipotRcEnable();

                // Approximately 0.1 V, assuming 3.3 nF, 2.7k resistance + 100k, 3.3V MSP
                timerUsDelayCycles(msp_config.vgaRcPrechargeCycles);
            }

            // Fix gain
            vgaDigipotFixGain();
            timerUsDelayStop();

            // Load the wiper code responsible for TGC gain slope
            if(msp_config.vgaRcGainSlopeWiperCode <= 255)
            {
                vgaDigipotSetWiperCode(msp_config.vgaRcGainSlopeWiperCode);
                vga_fixed_gain = 0;
            }
            else
            {
                vga_fixed_gain = 1;
            }


            // Configure TX config (applied immediately)
            hvMuxConfTx(msp_config.txConfigs[tx_rx_id]);

            // Check if TX and RX configs are identical
            if (msp_config.txConfigs[tx_rx_id] == msp_config.rxConfigs[tx_rx_id])
            {
                // Instruct the driver to ignore the next latch event
                hvMuxIgnoreNxtLatchEvt();
            }
            else
            {
                // Configure RX config (loaded into shift register but not latched)
                // Latching will occur in the timer interrupt after completion
                // of pulse generation
                hvMuxConfRx(msp_config.rxConfigs[tx_rx_id]);
            }
            // Switch HV pulser from HiZ to active state
            enableHvPulser();

            // Trigger ultrasound acquisition
            no_error = triggerUsAcq();
            if (no_error == false)
            {
                // Wait for timer to elapse
                waitTimerSlowElapse();
                continue;
            }

            // If instead acquisition sequencer finished as expected
            // and we reached this line, then
            // wait for the SPI DMA transaction to be completed

            // Wait for SPI DMA transmission to complete
            usWaitForSpiDmaRx();


            // Check the SPI RX buffer for restart command
            if (isRestartCondition(usSpiGetRxPtr()))
            {
//                pauseTimerSlowSwEvents();
                return;
            }

            // Wait for timer to elapse
            waitTimerSlowElapse();

            // Increment measurement frame number
            // And TX RX configuration ID
            meas_frame_nr++;
            tx_rx_id++;
            if(tx_rx_id == msp_config.txRxConfLen)
                tx_rx_id = 0;
    }
}

//// HELPER FUNCTIONS  ////

// Get configuration package from nRF
static void getConfigPack(void)
{
    // Initiate an SPI transaction to receive a config file
    // Clear TX buffer
    memset((uint16_t *) 0x4000, 0, (uint32_t)BYTES_PR_XFER_TX);
    memcpy((uint16_t *) 0x4000, firmware_hello, sizeof(firmware_hello));
    // Start SPI transaction
    usStartSPI();

    // Enable DMA SPI interrupt
    // It will wake up the CPU from LPM0
    usSpiEnableDmaRxIsr();

    // Wait for SPI DMA RX to be completed
    usWaitForSpiDmaRx();
}

//// Callbacks implementation ////
static void hsPllUnlockCallback(void)
{
    // TI recommends to turn off USS module and check USSXT oscillator

    pllUnlockCallback();
}

static void saphSeqAcqDoneCallback(void)
{

    // Power Down the UUPS after the acquisition is complete
    UUPSCTL |= USSPWRDN;

    // Disable HV PCB DC-DC converters
    // and OpAmp

//    // Disable HV and +5 V
//    disableHvPcbDcDc();
//    // Disable RX OPA836
//    disableOpAmp();

    // WULPUS Pro (17.04.25)
    disableAll();

    // SInk all charge from VGA gain input
    vgaDigipotSinkEnable();

    // if PLL unlock event occurs earlier the acquisition might be not valid
    if (isEventFlagSet(HS_PLL_UNLOCK_EVENT) == false)
    {
        // Enable DMA SPI interrupt
        // It will wake up the CPU from LPM0
        usSpiEnableDmaRxIsr();
        // Start SPI transaction
        usStartSPI();
    }
}

static void slowTimerCc2Callback(void)
{
//    // Turn On DC-DCs
//    enableHvPcbDcDc();
//    // Enable RX OPA836
//    enableOpAmp();


    // WULPUS PRO (17.04.25)
    enableAll();
}

static void fastTimerCc0Callback(void)
{

    // Switch HV Mux (has internal delay)
//    hvMuxLatchOutput();
    // New approach for faster latching
    hvMuxLatchHighToLow();

    // disable Pulser (switch to HiZ state)
    disableHvPulser();

    if (!vga_fixed_gain)
    {
        vgaDigipotRcEnable();
    }

    // New approach for faster latching
    hvMuxLatchLowToHigh();

    // Disable HV DC-DC (we don't need switching at this point)
//    disableHvDcDc();
    // Disable Fast Timer
    timerFastStop();
}

static void fastTimerCc2Callback(void)
{
    // Enable RC network for VGA gain control
//    vgaDigipotRcEnable();
}

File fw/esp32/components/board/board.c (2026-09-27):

/*
Copyright (C) 2026 Sergei Vostrikov

Licensed under the Apache License, Version 2.0 (the "License");
you may not use this file except in compliance with the License.
You may obtain a copy of the License at

    http://www.apache.org/licenses/LICENSE-2.0

Unless required by applicable law or agreed to in writing, software
distributed under the License is distributed on an "AS IS" BASIS,
WITHOUT WARRANTIES OR CONDITIONS OF ANY KIND, either express or implied.
See the License for the specific language governing permissions and
limitations under the License.
*/

/**
 * @file board.c
 * @brief Board GPIO, SPI, and USB light-sleep control.
 */

#include "board.h"

#include "bsp.h"
#include "esp_check.h"
#include "esp_pm.h"
#include "freertos/FreeRTOS.h"
#include "freertos/semphr.h"

static spi_device_handle_t spi_device;
static SemaphoreHandle_t spi_mutex;
#if CONFIG_WP_ENABLE_PM
static esp_pm_lock_handle_t usb_sleep_lock;
/* The C6 USB path corrupted command bytes and reported transient disconnects
 * with DFS down to 10 MHz. Keep CPU/APB clocks stable while USB is attached. */
static esp_pm_lock_handle_t usb_frequency_lock;
static bool usb_sleep_lock_held;
#endif

esp_err_t board_msp_reset(bool asserted)
{
    return gpio_set_level(CONFIG_WP_GPIO_MSP_RST_N, asserted ? 0 : 1);
}

bool board_data_ready(void)
{
    return gpio_get_level(CONFIG_WP_GPIO_DATA_READY) != 0;
}

esp_err_t board_data_ready_set_isr(gpio_isr_t handler, void* argument)
{
    esp_err_t result = gpio_install_isr_service(0);
    if (result != ESP_OK && result != ESP_ERR_INVALID_STATE) {
        return result;
    }
    return gpio_isr_handler_add(CONFIG_WP_GPIO_DATA_READY, handler, argument);
}

/**
 * @brief Serialize a SPI transaction and wait for its completion.
 */
static esp_err_t board_spi_transfer(const void* tx, void* rx, size_t length)
{
    if (xSemaphoreTake(spi_mutex, pdMS_TO_TICKS(1000)) != pdTRUE) {
        return ESP_ERR_TIMEOUT;
    }
    spi_transaction_t transaction = {
        .length = length * 8,
        .tx_buffer = tx,
        .rx_buffer = rx,
    };
    esp_err_t result = spi_device_queue_trans(spi_device, &transaction, portMAX_DELAY);
    if (result == ESP_OK) {
        spi_transaction_t* completed = NULL;
        result = spi_device_get_trans_result(spi_device, &completed, portMAX_DELAY);
    }
    xSemaphoreGive(spi_mutex);
    return result;
}

esp_err_t board_spi_receive_dma(void* buffer, size_t length)
{
    return board_spi_transfer(NULL, buffer, length);
}

esp_err_t board_spi_transmit(const void* buffer, size_t length)
{
    return board_spi_transfer(buffer, NULL, length);
}

esp_err_t board_spi_transceive(const void* tx_buffer, void* rx_buffer, size_t length)
{
    return board_spi_transfer(tx_buffer, rx_buffer, length);
}

esp_err_t board_usb_no_sleep_acquire(void)
{
#if CONFIG_WP_ENABLE_PM
    if (!usb_sleep_lock_held) {
        esp_err_t result = esp_pm_lock_acquire(usb_frequency_lock);
        if (result != ESP_OK)
            return result;
        result = esp_pm_lock_acquire(usb_sleep_lock);
        if (result != ESP_OK)
            esp_pm_lock_release(usb_frequency_lock);
        if (result == ESP_OK) {
            usb_sleep_lock_held = true;
        }
        return result;
    }
#endif
    return ESP_OK;
}

esp_err_t board_usb_no_sleep_release(void)
{
#if CONFIG_WP_ENABLE_PM
    if (usb_sleep_lock_held) {
        esp_err_t result = esp_pm_lock_release(usb_sleep_lock);
        if (result == ESP_OK) {
            esp_pm_lock_release(usb_frequency_lock);
            usb_sleep_lock_held = false;
        }
        return result;
    }
#endif
    return ESP_OK;
}

esp_err_t board_init(void)
{
    ESP_RETURN_ON_ERROR(bsp_init(), "board", "BSP initialization failed");

    gpio_config_t gpio = {
        .intr_type = GPIO_INTR_DISABLE,
        .mode = GPIO_MODE_OUTPUT_OD,
        .pin_bit_mask = 1ULL << CONFIG_WP_GPIO_MSP_RST_N,
        .pull_down_en = GPIO_PULLDOWN_DISABLE,
        .pull_up_en = GPIO_PULLUP_DISABLE,
    };
    ESP_RETURN_ON_ERROR(gpio_config(&gpio), "board", "MSP reset GPIO failed");
    ESP_RETURN_ON_ERROR(board_msp_reset(true), "board", "MSP reset failed");
    ESP_RETURN_ON_ERROR(gpio_sleep_sel_dis(CONFIG_WP_GPIO_MSP_RST_N), "board",
                        "MSP sleep GPIO failed");

    gpio = (gpio_config_t){
        .intr_type = GPIO_INTR_POSEDGE,
        .mode = GPIO_MODE_INPUT,
        .pin_bit_mask = 1ULL << CONFIG_WP_GPIO_DATA_READY,
        .pull_down_en = GPIO_PULLDOWN_ENABLE,
        .pull_up_en = GPIO_PULLUP_DISABLE,
    };
    ESP_RETURN_ON_ERROR(gpio_config(&gpio), "board", "DATA_READY GPIO failed");
    ESP_RETURN_ON_ERROR(gpio_sleep_set_direction(CONFIG_WP_GPIO_DATA_READY, GPIO_MODE_INPUT),
                        "board", "DATA_READY sleep direction failed");
    ESP_RETURN_ON_ERROR(gpio_sleep_set_pull_mode(CONFIG_WP_GPIO_DATA_READY, GPIO_PULLDOWN_ONLY),
                        "board", "DATA_READY sleep pull failed");

    spi_bus_config_t bus = {
        .miso_io_num = CONFIG_WP_SPI_MISO,
        .mosi_io_num = CONFIG_WP_SPI_MOSI,
        .sclk_io_num = CONFIG_WP_SPI_CLK,
        .quadwp_io_num = -1,
        .quadhd_io_num = -1,
        .max_transfer_sz = CONFIG_WP_SPI_MAX_TRANSFER_SIZE,
    };
    spi_device_interface_config_t device = {
        .clock_speed_hz = CONFIG_WP_SPI_CLOCK_SPEED,
        .mode = 1,
        .spics_io_num = CONFIG_WP_SPI_CS,
        .queue_size = 3,
        .cs_ena_pretrans = 16,
        .cs_ena_posttrans = 16,
    };
    ESP_RETURN_ON_ERROR(spi_bus_initialize(CONFIG_WP_SPI_INSTANCE - 1, &bus, SPI_DMA_CH_AUTO),
                        "board", "SPI bus failed");
    ESP_RETURN_ON_ERROR(spi_bus_add_device(CONFIG_WP_SPI_INSTANCE - 1, &device, &spi_device),
                        "board", "SPI device failed");
    spi_mutex = xSemaphoreCreateMutex();
    if (spi_mutex == NULL) {
        return ESP_ERR_NO_MEM;
    }
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

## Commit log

2026-09-27 chore: add firmware and PCB release packaging scripts
2026-09-27 feat: package and verify MSP430 release ZIPs
    - bundle firmware checksums and TI compliance notices
    - validate MSP430 ZIPs before upload
    - update the firmware GUI, notebook, and documentation
    - add package validation tests and missing license headers
    [esp32_update.py, msp430_update.py]
2026-10-12 build(desktop-gui): add development and release tooling
    - add Ruff formatting and lint checks
    - add PyInstaller portable and one-file builds
    - derive executable names and metadata from the software version
    - add release packaging with SHA-256 checksum generation
    - add CI formatting and offline GUI tests
    - document build, packaging, and smoke-test commands
    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
2026-10-12 fix(esp32): preserve MSP430 version across acquisition restarts
2026-10-12 chore(release): prepare software 0.3.0 and ESP32 1.2.1 versions and changelogs
2026-10-27 docs: add USB and wireless operating modes guide
2026-10-29 docs: add MkDocs documentation prototype
2026-10-29 docs: improve replication and firmware guides
    - clarify hardware ordering and replication steps
    - refine firmware update notes and warnings
    - unify automatic tables of contents
    - rename navigation sections and desktop application page
    - add acquisition and WiFi host PCB images
    - reorder home page getting-started links
2026-11-08 fix(esp32): stop Wi-Fi before retrying failed credential changes
2026-11-08 feat(gui): add selectable ESP32 flashing backends
2026-11-08 feat(gui): show progress states on action buttons
2026-11-08 chore(release): bump ESP32 firmware to 1.2.2
2026-11-08 fix(esp32): enable provisioning security 1 in clean builds
